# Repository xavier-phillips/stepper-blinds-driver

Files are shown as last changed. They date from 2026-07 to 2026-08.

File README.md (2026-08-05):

<div align="center">

# stepper-blinds-driver

**An ultra-quiet NEMA 17 retrofit driver for beaded-chain roller blinds.**

Xavier Phillips









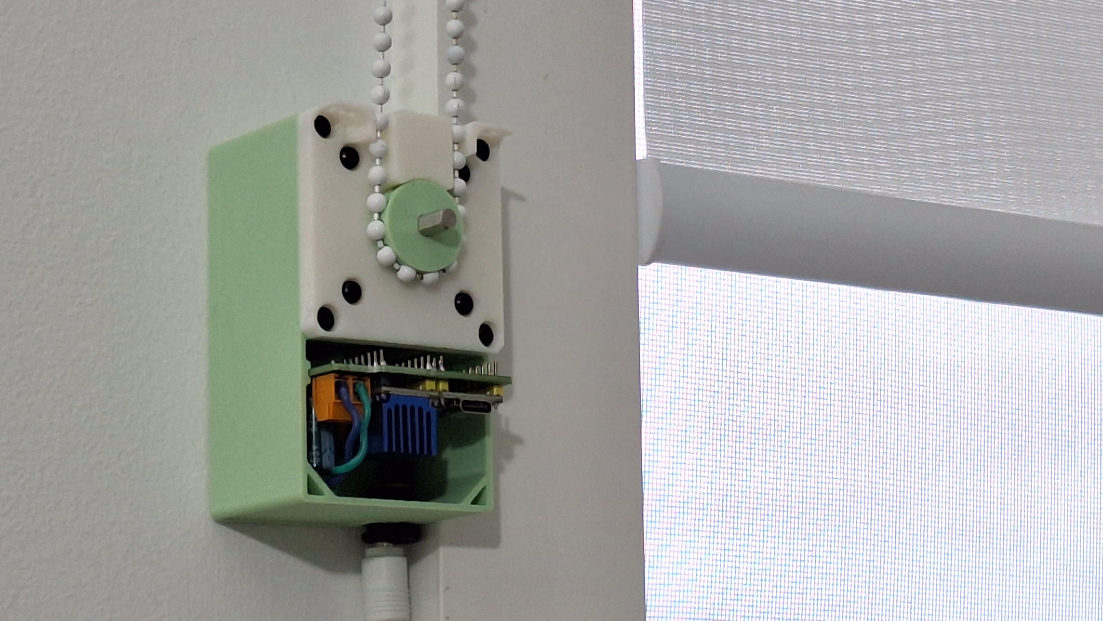
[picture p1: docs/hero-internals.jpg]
Finished device

_The stepper blinds driver with the top lid removed, showing the main sprocket and the custom PCB._

</div>

---

## Contents
- [Overview](#overview)
- [Project Snapshot](#project-snapshot)
- [Technical Skills](#technical-skills)
- [Key Design Decisions](#key-design-decisions)
- [Hardware](#hardware)
- [Control Software](#control-software)
- [Build Log](#build-log)
- [Testing](#testing)
- [What's Next](#whats-next)
- [Reflection](#reflection)
- [Documentation](#documentation)

---

## Overview

### Problem
Opening blinds automatically has a range of benefits:
- Easier to wake up in mornings, and aligns circadian rhythm
- Provides more sunlight during day (for an office, this helps improve mood, among other health benefits)

Commercial options have some limitations:
- Can be very expensive
- Almost all commercial devices use geared DC motors, and are very loud when in operation (>50dB)

### Goal
1. Low-cost (<$100)
2. Compatible with beaded-chain blinds
3. Near-silent (<40dB)

### Features
1. Actuate beaded-chain with positional control (e.g. set to 50%)
   2. High precision is not crucial, aside from the start and end positions. However, end position is a mechanical limit (blinds cannot go further than highest position).
3. Controlled via Google Home or Home Assistant for scheduled automations.
4. Device should be compact
5. Powered externally with power supply (extremely clean, minimal, easy to hide cable)
6. Buttons should be minimised for aesthetic
   7. Possible structure
      1. Ver. 1 - up/down pushbuttons, power toggle. accessible port for microcontroller. no PCB (wires)
      2. Ver. 2 - power toggle only - small, hidden same-colour micro latch switch. hidden port for microcontroller (possibly a friction fit soft tpu plastic cover for it or similar, like a port cover, same colour). PCB.
8. Easily replaceable components (motor, PCB, microcontroller). highest priority for replicability is the cog/sprocket for the beaded chain which MUST be hot swappable in seconds
9. Custom PCB for final product
10. Clean, minimal box design with all internals hidden, mountable to a wall with standard screws

---

## Project Snapshot

### Details

| **Type** | Personal project (no course/folio behind it) |
| --- | --- |
| **Duration** | Started ~30 June 2026, ongoing |
| **Budget** | $90.42 true project cost (target: <$100) |
| **Mechanism** | Beaded-chain actuation, positional control (e.g. set to 50%) |
| **MCU / Control** | ESP32-C6 Mini Dev Board (Serial CLI Firmware v1.0) |
| **Motor / driver** | NEMA 17 Stepper Motor (34mm, 1.5A) + TMC2209 V2.0 Stepper Driver |
| **PCB** | Custom 2-layer PCB for all electrical components |
| **Mechanical CAD** | Onshape |
| **Manufacturing** | 3D printing |

### Specifications

| Spec | Value |
| --- | --- |
| Required pulling force | 1.8kg (bucket-tested - see build log) |
| Noise target | <40dB (commercial cheap models are >50dB) |
| Travel range | Unlimited |
| Holding torque | N/A, designed for counterbalanced or friction-balanced household blinds |
| Power supply | 12V 3A 36W power supply |
| Ecosystem tested against | Google Home or Home Assistant (per scope - not yet tested) |

---

## Technical Skills

| Area | Skills and tools |
| --- | --- |
| Mechanical design | Onshape CAD - hot-swappable cog/sprocket mount for the beaded chain, compact enclosure |
| PCB design | KiCad - custom PCB for final product (goal #7); V1 currently using off-the-shelf breakouts (TMC2209 driver module, MP1584EN buck converter) on a prototype board |
| Embedded programming | C++ / Arduino on ESP32 (Non-blocking stepper driver integration) |
| Smart home integration | Google Home or Home Assistant, for scheduled automations |
| Manufacturing | 3D printing |

---

## Key Design Decisions

| Decision | Options considered | Reasoning |
| --- | --- | --- |
| Motor + driver | Ranked 10 motor setups against the <40dB noise / <$100 cost constraints (full comparison below); shortlisted NEMA 17 + TMC2209, JGY-370 Worm Gear Motor, NEMA 17 (5:1 Planetary Geared) + TMC2209 | This motor is extremely well documented and has a low noise level when paired with the TMC2209 controller. |
| PCB / prototyping approach | Off-the-shelf breakout modules (TMC2209 driver, MP1584EN buck converter) on a prototype board vs. a from-scratch custom PCB | V1 is on protoboard for now; custom PCB for final product is goal #7 |
| Button / enclosure interface | Minimal-none. The device is intended to be controlled wirelessly in the final iteration. Prototypes are controlled via serial CLI. | Buttons should be minimised for aesthetic (goal #5) |

<details>
<summary><strong>Full motor comparison</strong> (from motor research notes)</summary>

> The biggest constraints for the motor are the <40dB requirement and the cost (total cost <$100)

**What impacts motor noise?**
- DC Brushed Motors - Brush scratching
- Geared Motors - Vibrations and friction
- Magnetic hum & coil whine

Overall, the magnitude of these sounds is also proportional to the RPM of the motor, so a slower RPM motor is ideal (and has the additional advantage of making the change in light level more gradual)

| Rank | Motor Setup | Category | Torque (Nm) | Max RPM | RPM Notes | Self-Locking | Approx. Noise Level (dB) | Dimensions (mm) | Volume (cm³) |
|---|---|---|---|---|---|---|---|---|---|
| 1 | NEMA 17 (Standard 42mm) + TMC2209 | Stepper | 0.40 | 400 | Variable | No | 38 | 42.3 x 42.3 x 40.0 | 71.57 |
| 2 | JGY-370 Worm Gear Motor (12V) | Brushed DC | 1.00 | 40 | Gearbox Fixed | Yes | 42 | 76.8 x 32.0 x 25.2 | 61.93 |
| 3 | NEMA 17 (5:1 Planetary Geared) + TMC2209 | Stepper | 1.50 | 80 | Variable | No | 43 | 42.3 x 42.3 x 61.3 | 109.68 |
| 4 | 35BYJ46 Geared Stepper (12V) | Stepper | 0.30 | 30 | Variable | No | 38 | 35.0 x 35.0 x 17.2 | 21.07 |
| 5 | BGM4108 Gimbal Motor + SimpleFOC | BLDC | 0.20 | 400 | Variable | No | 32 | 46.0 x 46.0 x 24.0 | 50.78 |
| 6 | 12V 28BYJ-48 (Modified to Bipolar) | Stepper | 0.10 | 15 | Variable | No | 35 | 28.0 x 28.0 x 19.0 | 14.90 |
| 7 | 25GA-370 Gear Motor (12V) | Brushed DC | 0.50 | 60 | Gearbox Fixed | No | 45 | 25.0 x 25.0 x 52.0 | 32.50 |
| 8 | NEMA 14 + TMC2209 Driver | Stepper | 0.15 | 400 | Variable | No | 38 | 35.0 x 35.0 x 26.0 | 31.85 |
| 9 | N20 Micro Gearmotor (12V, 60 RPM) | Brushed DC | 0.25 | 60 | Gearbox Fixed | No | 45 | 26.0 x 12.0 x 10.0 | 3.12 |
| 10 | MG996R Continuous Rotation Servo | Servo | 0.90 | 100 | Variable | No | 50 | 40.7 x 19.7 x 42.9 | 34.40 |

**Shortlist**

*1. NEMA 17 + TMC2209* - This motor is extremely well documented and has a low noise level when paired with the TMC2209 controller.

*2. JGY-370 Worm Gear Motor* - This is a slightly louder, more powerful alternative to the NEMA, the second best option if the NEMA turns out to be underpowered in torque (0.40 Nm vs 1.00 Nm). Has an additional benefit of being self-locking. Slightly above the noise limit by 2dB which is an acceptable margin.

*3. NEMA 17 (5:1 Planetary Geared) + TMC2209* - Same motor as Option 1, but geared to increase torque and reduce max RPM. Similar noise level and torque to Option 2, but ranked lower due to increased complexity.

</details>

---

## Hardware

### Mechanical (Onshape)
The main mechanical component is the mount, featuring two compartments. A thick-walled compartment which is load-bearing and contains the NEMA17, in addition to a thin-walled circuit compartment. 

To connect the NEMA17 to the mount, there is a face plate, which also features guides for the beaded-chain to be routed through.

There's also a cosmetic lid which is friction-fit using two pins for alignment and security, hiding the internal circuit while being easy to remove.

The sprocket is parametrically designed based on the following formulas.

The box features hexagonal ventilation holes which balance structural integrity and FDM manufacturability with sufficient surface area for thermal convection to prevent overheating.

### Electronics (KiCad)
The electronics involved in this project are for controlling and powering the motor. The ESP32 is the brain, allowing programmed movement logic and eventually communication with Google Home and other smart home systems via Matter over WiFi. The TMC2209 acts as an interface between the ESP32 and the NEMA17, and via the StealthChop2 feature, it allows ultra-quiet motor movement. The MP1584EN is a simple buck converter to step down the 12V from the power supply to the 5V required for the ESP32. 

I decided to use a custom PCB because I wanted to make multiple of the device, and eventually open-source it, so I decided inserting components into a PCB would be much easier than wiring spaghetti and frustrating breadboarding. It also gave me a chance to upskill KiCAD and learn about circuit schematics, rule checkers, and the PCB development and manufacturing process.

**BOM**

| Component | Source | Pack Size (Bought) | Qty Required | Pack Cost (AUD) | True Project Cost (AUD) |
|---|:---:|:---:|:---:|:---:|:---:|
| ESP32-C6 Mini Dev Board | Amazon AU | 1 | 1 | $25.01 | $25.01 |
| 12V 3A 36W Power Supply | Amazon AU | 1 | 1 | $21.99 | $21.99 |
| NEMA 17 Stepper Motor (34mm, 1.5A) | Amazon AU | 1 | 1 | $20.99 | $20.99 |
| TMC2209 V2.0 Stepper Driver | Amazon AU | 5 | 1 | $37.03 | $7.41 |
| MP1584EN 3A DC-DC Buck Converter | Amazon AU | 15 | 1 | $18.87 | $1.26 |
| Custom 2-Layer PCB | JLCPCB | 5 | 1 | $2.00 | $0.40 |
| M3 Button Head Screw Kit | Amazon AU | 300 | 8 | $10.99 | $0.29 |
| M3 Nylon Standoffs & Nuts Kit | Amazon AU | 320 | 4 | $12.99 | $0.16 |
| 3M VHB Double Sided Tape | Amazon AU | 33m | 10 cm | $12.99 | $0.04 |
| 2.1mmx5.5mm DC Power Jack (Panel Mount) | Amazon AU | 30 | 1 | $16.89 | $0.56 |
| 100µF 50V Electrolytic Capacitor (Polarized) | Jaycar Electronics | 1 | 1 | $1.00 | $1.00 |
| 60/40 Rosin Core Solder 0.71mm | Workshop | 15g | Variable | $0.00 | $0.00 |
| 24 AWG Solid Core Hookup Wire | Workshop | N/A | Variable | $0.00 | $0.00 |
| **Totals** | | | | **$180.75** | **$79.11** |

---

## Control Software
I wanted to keep this deliberately simple and write it fully myself so I could understand how the stepper control loop works, rather than relying on agentic tools to write something complex that I wouldn't fully understand under the hood.

**What it does:**
- Serial-based control to move to a pre-defined top and bottom position for the blinds
- Pause command to cancel movement with smooth acceleration.

**What it deliberately doesn't do (and why):**
- Other features (e.g. Matter over WiFi, auto calibration) have been left out due to time constraints for now and will be developed further in the future.

**Walkthrough**

* **`read_int()`:** Serial user input parser that checks for user commands and accepts valid inputs as commands (`0: Stop`, `1: Top`, `2: Bottom`).
* **`FastAccelStepper` Engine:** Asynchronously drives the STEP/DIR signal generation using ESP32 hardware timers, allowing smooth acceleration and deceleration ramps in the background.

---

# Build Log

### 2026-06-30 - Measuring required pull force

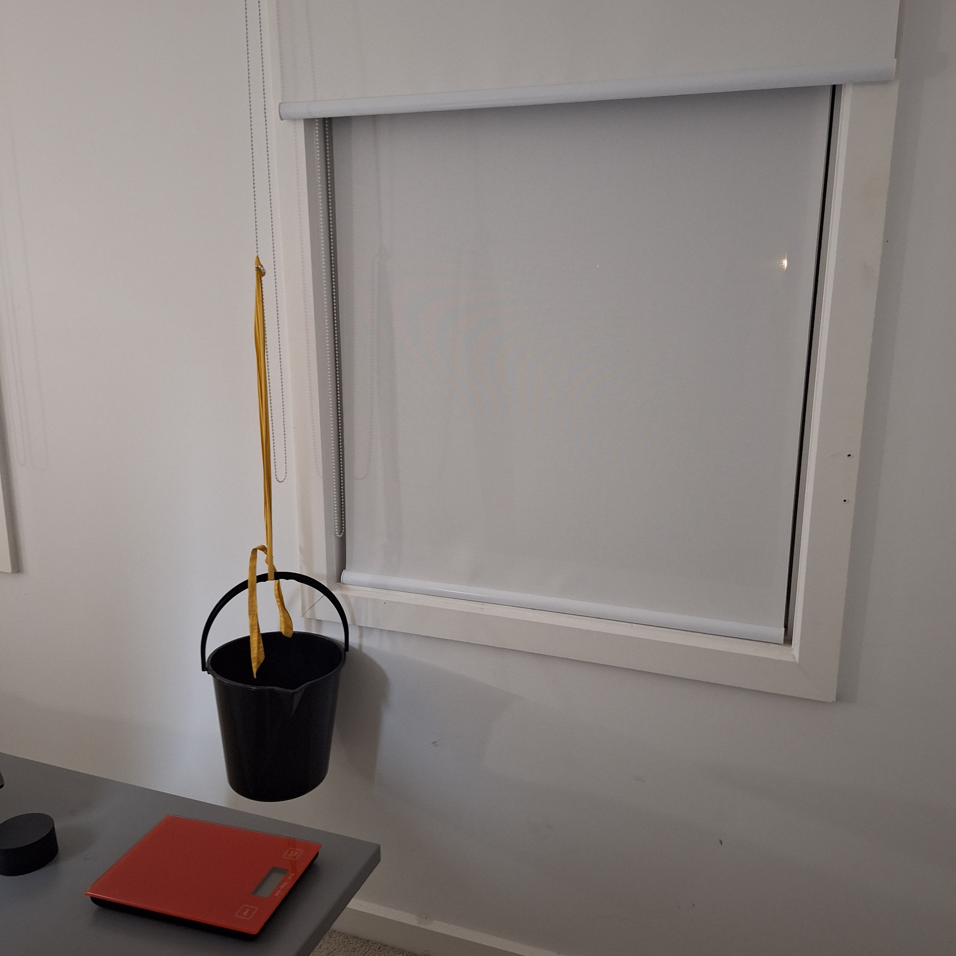
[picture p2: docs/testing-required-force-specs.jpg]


- Used a water bucket attached to the blinds to measure the force required to move them.
- At 1.7 kg, the blinds remained stationary. At 1.8 kg, the blinds were able to move.
- The 20 mm NEMA17 was determined to have insufficient torque, leading to the decision to use the 34 mm NEMA17 instead.

### 2026-07-02 - Initial CAD design

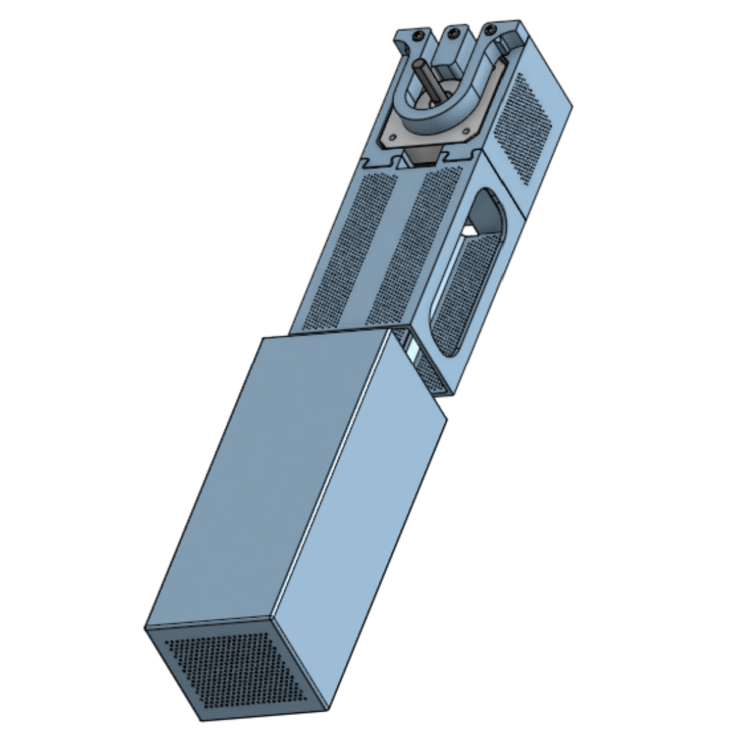
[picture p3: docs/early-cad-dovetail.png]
Initial CAD design


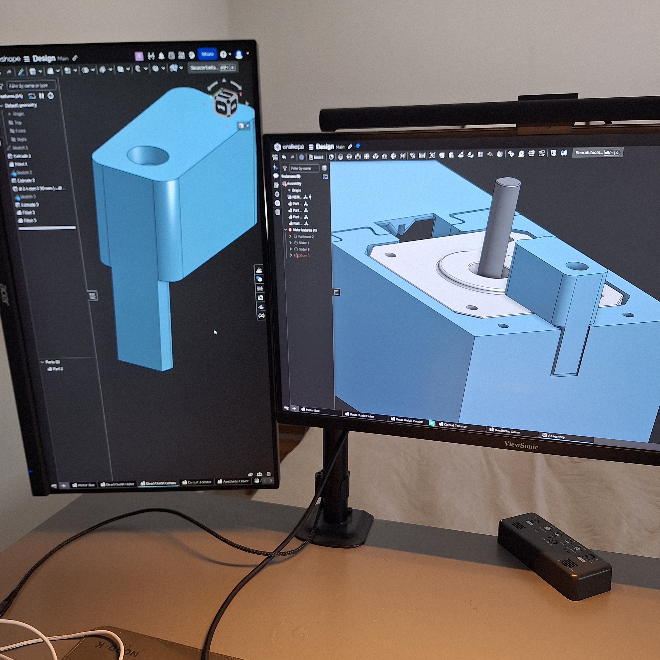
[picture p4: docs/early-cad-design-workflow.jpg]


 - This design has a removable circuit box area, using dovetail cutouts. It also has removable guides for the beaded chains, secured by M2 screws.

### 2026-07-05 - Perfboard Assembly

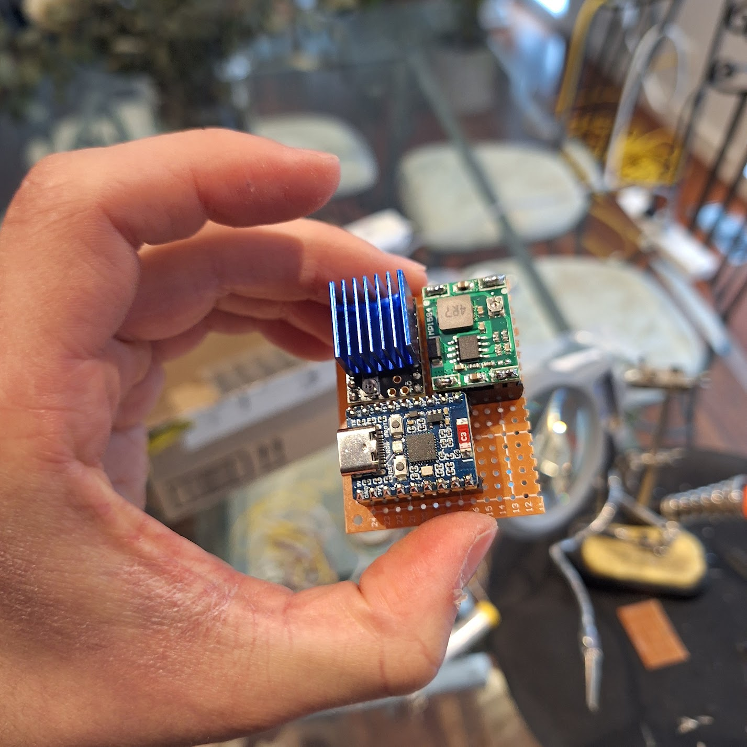
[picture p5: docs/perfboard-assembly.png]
Perfboard Assembly


 - Image of the components laid out on a perfboard. I've cut the perfboard down to a smaller size for compactness in this image, but for later perfboard iterations I used the full size, just for ease of wiring and troubleshooting (since it was only a prototype, the compactness was evaluated as somewhat irrelevant)

### 2026-07-07 - PCB Design 1

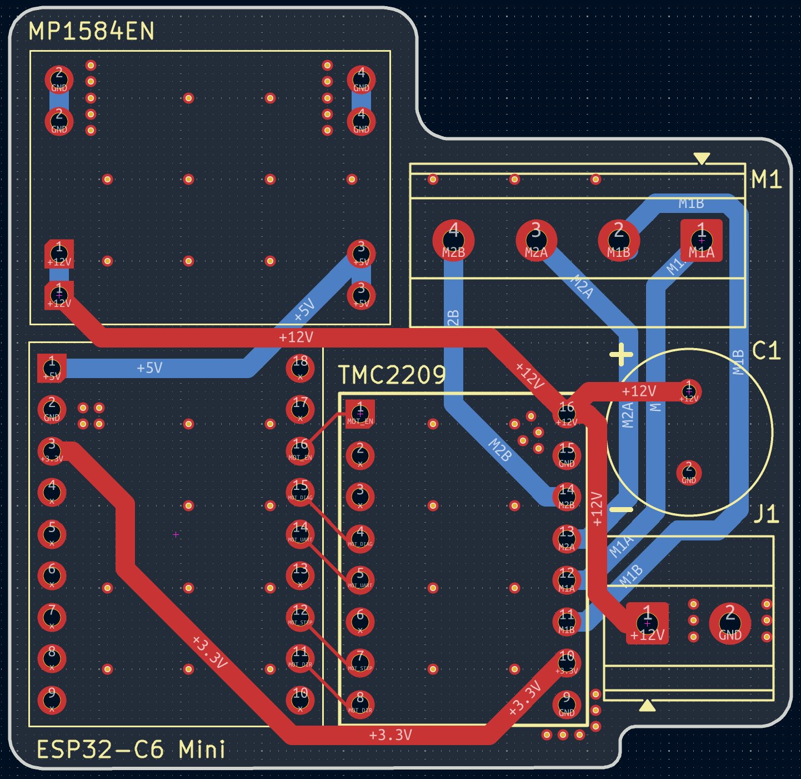
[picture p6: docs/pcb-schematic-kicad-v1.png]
PCB Design 1


### 2026-07-10 - PCB Design 2

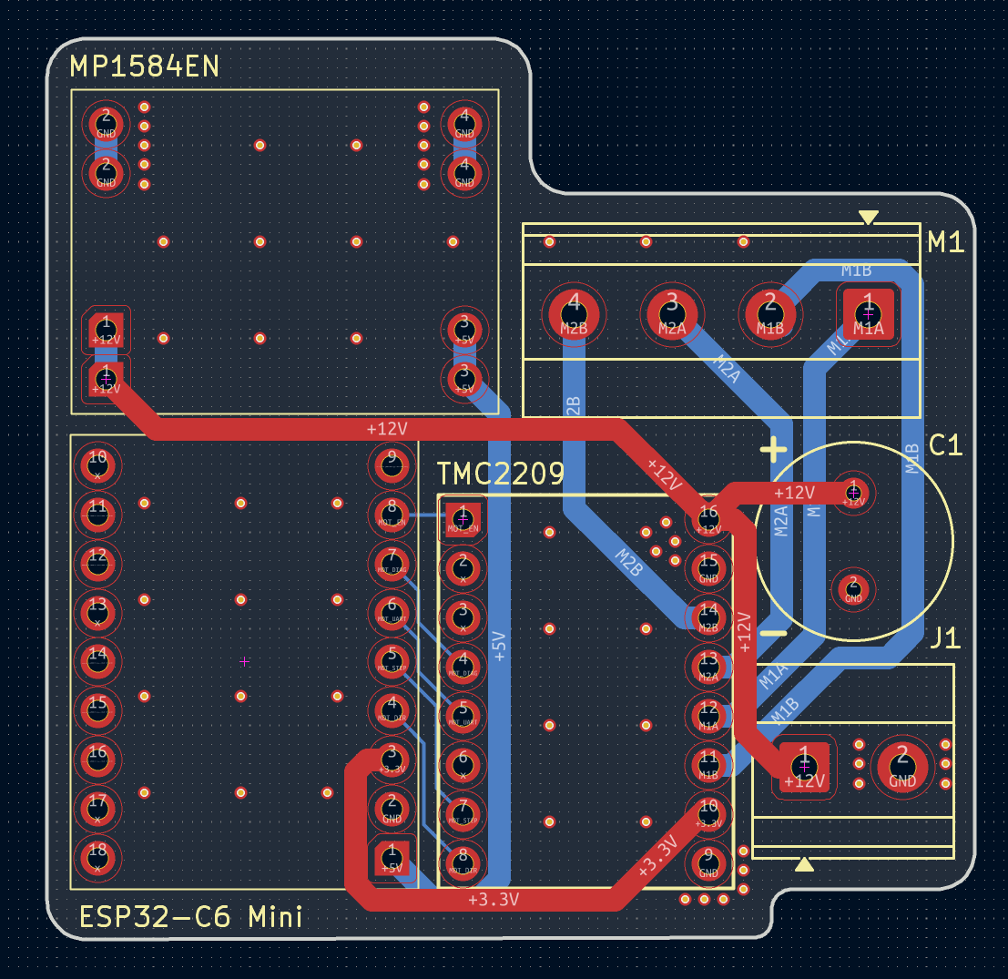
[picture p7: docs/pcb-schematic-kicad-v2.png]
PCB Design 2


- Modified the PCB schematic in KiCAD to flip the footprint of the ESP32C6 by 180 degrees. This ensures that it can be wired correctly while having the USB port point towards the edge of the board, instead of the centre. Code was also updated to reflect the new pins.

### 2026-07-21 - Control Software Draft

```cpp
#include <Arduino.h>
#include <FastAccelStepper.h>

constexpr int PIN_EN = 14;
constexpr int PIN_SPREAD = 15;
constexpr int PIN_UART = 18;
constexpr int PIN_STEP = 20;
constexpr int PIN_DIR = 21;

constexpr int SPEED = 500;  // step per sec
constexpr int ACCEL = 1000; // step per sec^2

constexpr int TOP_POSITION = 0;       // steps
constexpr int BOTTOM_POSITION = 1000; // steps

enum user_input
{
  PAUSE,
  TOP,
  BOTTOM,
  OPTIONS_COUNT
};

user_input command = PAUSE;

int read_int()
{
  int command = -1;

  if (Serial.available() > 0)
  {
    command = Serial.parseInt();

    Serial.printf("Command received: %d\n", command);
  }

  return command;
};

FastAccelStepperEngine engine = FastAccelStepperEngine();
FastAccelStepper *stepper = nullptr;

void setup()
{
  pinMode(PIN_STEP, OUTPUT);
  digitalWrite(PIN_SPREAD, LOW);

  Serial.begin(115200);
  delay(1000);

  engine.init();

  stepper = engine.stepperConnectToPin(PIN_STEP);

  if (stepper)
  {
    Serial.println("SUCCESS: Stepper connected!");

    stepper->setDirectionPin(PIN_DIR);
    stepper->setEnablePin(PIN_EN);
    stepper->setAutoEnable(true);
    stepper->setSpeedInHz(SPEED);
    stepper->setAcceleration(ACCEL);
    stepper->setCurrentPosition(0);
  }
  else
  {
    Serial.println("ERROR: Stepper failed to connect.");
  }
}

void loop()
{

  command = static_cast<user_input>(read_int());

  if (command != -1)
  {
    Serial.printf("Current Position: %d Enter an option:\n\t0.Pause\n\t1. Move Top\n\t2. Move Bottom\n", stepper->getCurrentPosition());

    switch (command)
    {
    case PAUSE:
      Serial.println("Action: STOP");
      stepper->stopMove();
      break;

    case TOP:
      Serial.println("Action: TOP");
      stepper->moveTo(TOP_POSITION, false);
      break;

    case BOTTOM:
      Serial.println("Action: BOTTOM");
      stepper->moveTo(BOTTOM_POSITION, false);
      break;

    default:
      Serial.printf("Invalid command! Enter a valid integer between 1 and %d.\n", OPTIONS_COUNT);
      break;
    }
  }
}
```
 - Just a basic serial-control script for testing basic functionality (movement up, down, and pausing)

### 2026-07-24 - CAD Design 2

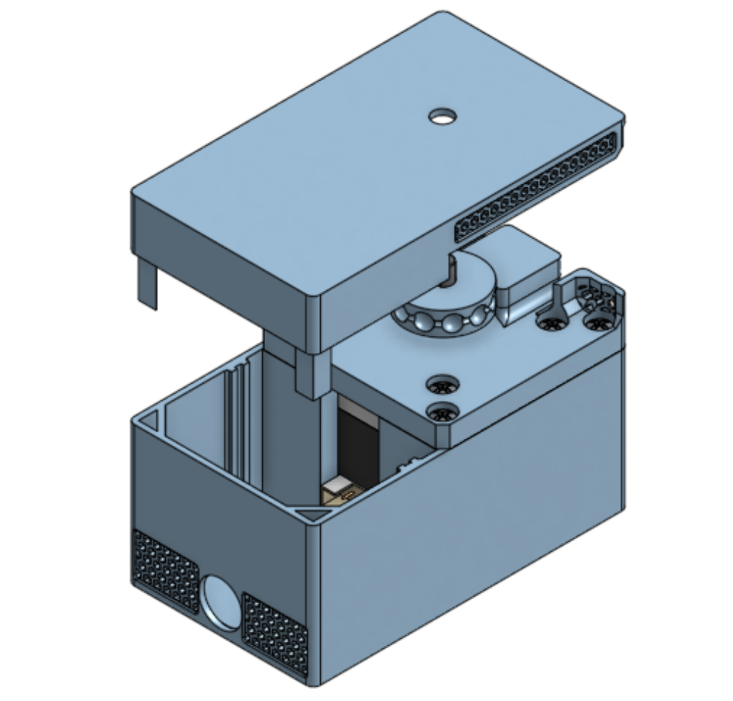
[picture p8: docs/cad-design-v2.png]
CAD Design 2


 - This was a major transition. The two-box dovetail architecture was replaced with a single box with two compartments. 

### 2026-07-30 - Motor Testing

- Upon arrival of the board (**2026-07-30**) and initial basic testing of roller blind movement (a short test program), I determined that the NEMA17 tended to stall quite easily. Upon closer inspection and troubleshooting (including verifying that it did work with a much lighter, smaller roller blind), I determined that the cause was simply insufficient current. The 12V wall adapter I was using only had a rated current of 1A, much less than the planned 3A.
- Order a 12V 3A power supply ASAP, in order to provide sufficient power for the NEMA17 to lift basic blinds.

---

## Testing

| Test | Result |
| --- | --- |
| Bucket test - required pulling force | 1.8kg confirmed |
| Noise level (<40dB target) | Not yet tested  |

---

## What's Next

- The next step is writing the implementation that includes Matter, rather than the basic hard-coded values the script currently uses. 
	- For the implementation, I want to keep it buttonless for aesthetics and simplicity of circuitry. So I'm planning to use StallGuard to determine increased resistance at the top of the range of motion (ROM) for calibration, as well as a reduced resistance at the bottom of ROM.

---

## Reflection

I learned a massive amount from this project. On the CAD side, I learned about using variables in my designs, rather than "magic numbers" for dimensions, so everything in my design is fully adjustable via the variables table. I also learned about a lot more Onshape's sketch tools (tangent, normal, and perpendicular constraints), as well as their 3D tools (Featurescripts like Grid Extrude for ventilation, alongside operations like revolve which I used for the sprocket). 

I also learned KiCAD from scratch during this project, which was a great learning experience and upskilling opportunity into a new field. Historically I used graphical software like Canva or Illustrator for circuit diagrams, but learning how to write proper, verified schematics was really enjoyable, and seeing my own custom-designed PCB arrive was extremely rewarding. Contrary to what I used to assume about PCBs, it actually _saved_ me time, as I used to have to spend weeks fiddling with breadboards because I didn't take the time to plan my circuit thoroughly. That, combined with the time saved from soldering (only took ~10min to solder the entire PCB!), allowed me to finalise all electronics in about a week.

---

## Documentation

- Firmware Code: [`/firmware`](firmware/)
- PCB (Schematic + Gerbers): [`/hardware/pcb`](hardware/pcb/)
- CAD Files: [`/hardware/cad`](hardware/cad/)

## Acknowledgements & License

[gin66/FastAccelStepper: A high speed stepper library for Atmega 168/328p (nano), Atmega32u4, Atmega 2560, ESP32, ESP32S2, ESP32S3, ESP32C3, ESP32C6, Atmel SAM Due, Raspberry pi pico and pico 2](https://github.com/gin66/FastAccelStepper)

This project is licensed under the MIT License. See the [LICENSE](LICENSE) file for details.

<p align="center"><sub>Personal project, July 2026.</sub></p>

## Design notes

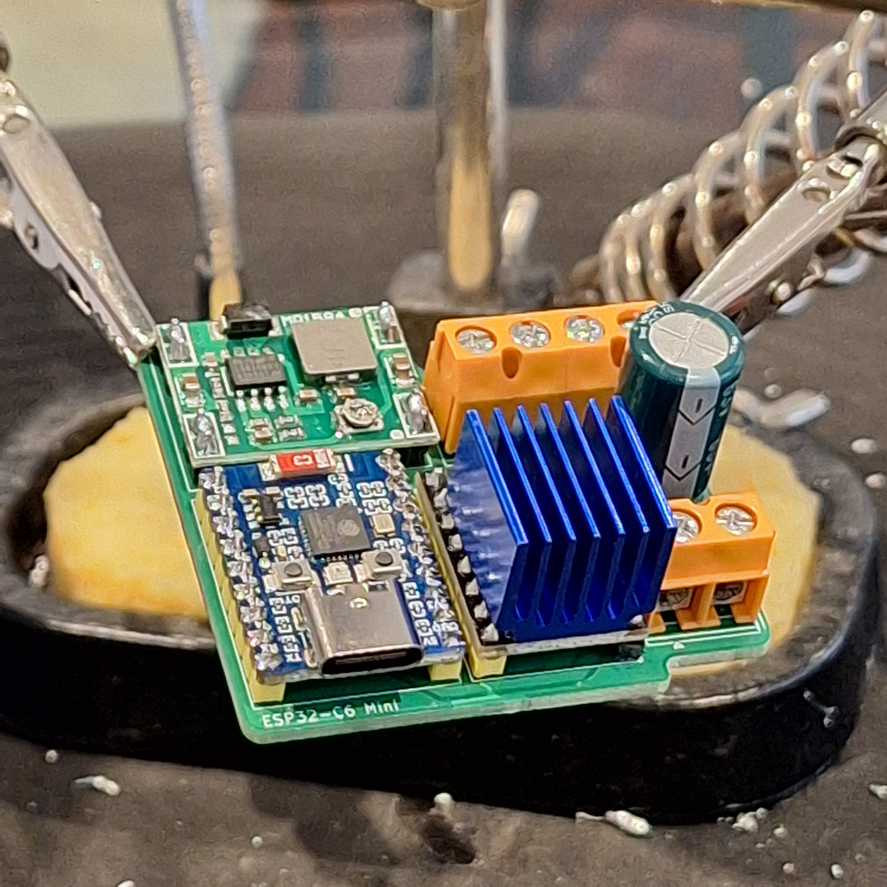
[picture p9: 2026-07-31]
docs/completed-pcb.jpg

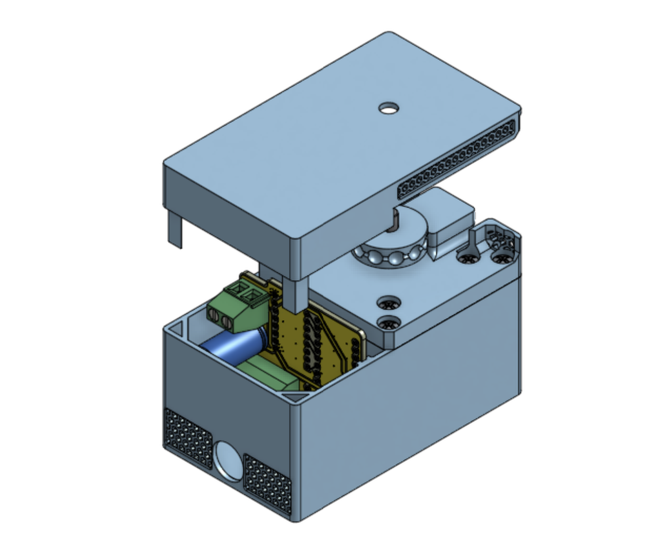
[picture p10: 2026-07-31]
docs/hero-uncovered.png

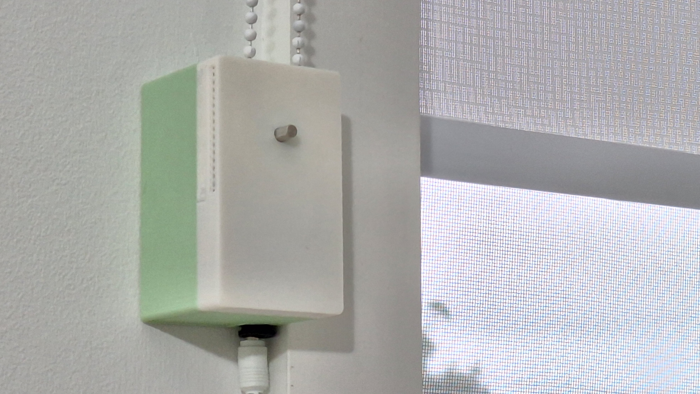
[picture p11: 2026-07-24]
docs/hero-covered.jpg

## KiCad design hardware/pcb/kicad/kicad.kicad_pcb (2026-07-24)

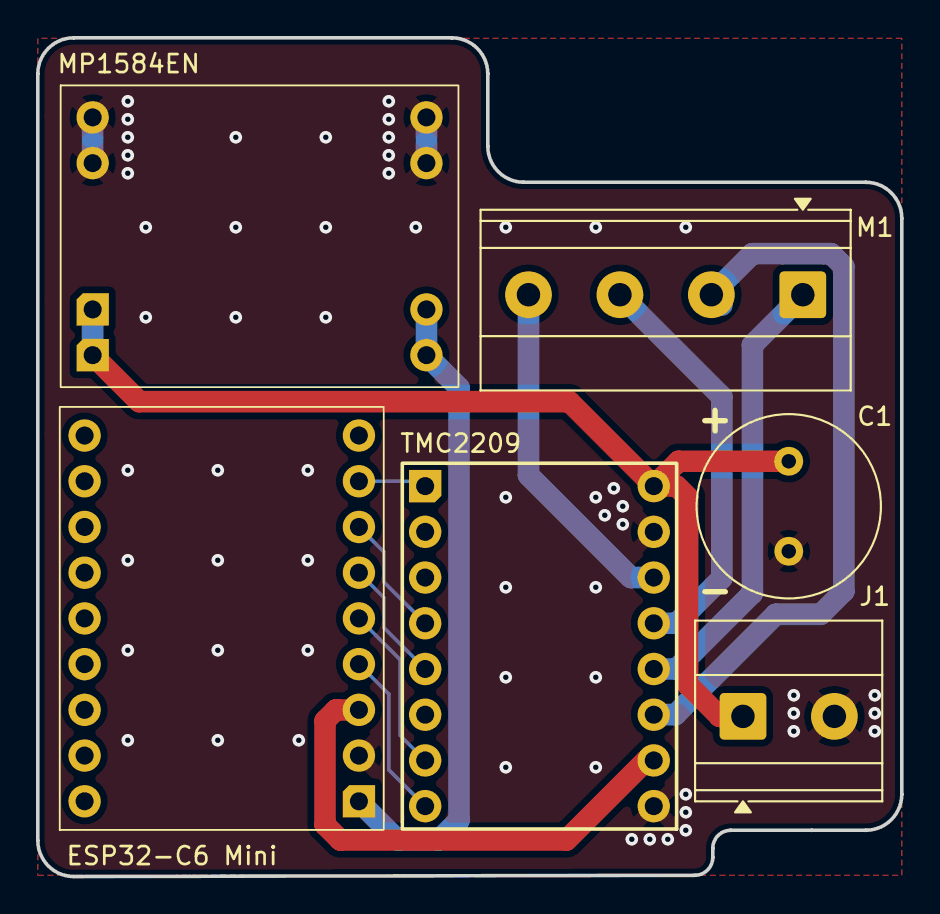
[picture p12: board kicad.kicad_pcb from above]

Board: 2 copper layers, 48.0 x 46.6 mm, 6 parts (0 on the bottom side), 13 nets.

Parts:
C1: 100µF; C_Radial_D10.0mm_H20.0mm_P5.00mm
ESP32-C6-Super-Mini1: ESP32-C6-Super-Mini-Header
J1: Barrel_Jack; TerminalBlock_Phoenix_MKDS-1,5-2-5.08_1x02_P5.08mm_Horizont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
M1: Stepper_Motor_bipolar; TerminalBlock_Phoenix_MKDS-1,5-4-5.08_1x04_P5.08mm_Horizont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
MP1584EN1: MP1584EN-Module
TMC2209: TMC2209-Module

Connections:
+3.3V: ESP32-C6-Super-Mini1.3 (3V3), TMC2209.10 (VIO)
+5V: ESP32-C6-Super-Mini1.1 (5V), MP1584EN1.3 (OUT+)
+12V: C1.1, J1.1, MP1584EN1.1 (IN+), TMC2209.16 (VM)
/M1A: M1.1, TMC2209.12 (M1A)
/M1B: M1.2 (-_2), TMC2209.11 (M1B)
/M2A: M1.3, TMC2209.13 (M2A)
/M2B: M1.4, TMC2209.14 (M2B)
/MOT_DIAG: ESP32-C6-Super-Mini1.7 (GP3), TMC2209.4 (SPREAD)
/MOT_DIR: ESP32-C6-Super-Mini1.4 (GP0), TMC2209.8 (DIR)
/MOT_EN: ESP32-C6-Super-Mini1.8 (GP4), TMC2209.1 (EN)
/MOT_STEP: ESP32-C6-Super-Mini1.5 (GP1), TMC2209.7 (STEP)
/MOT_UART: ESP32-C6-Super-Mini1.6 (GP2), TMC2209.5 (PDN_UART1)
GND: C1.2, ESP32-C6-Super-Mini1.2 (GND), J1.2, MP1584EN1.2 (IN-), MP1584EN1.4 (OUT-), TMC2209.9 (GND), TMC2209.15 (GND)

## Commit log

2026-07-25 Added CAD README
2026-08-05 Update BOM
2026-10-13 Correct overstated claims in README
    Match the README to the project record: skewer picking and laptop detection (AutoBerryPicker), calculated rather than measured force (exoARM), unmeasured noise and the shipped custom PCB (stepper-blinds-driver).
2026-10-17 Distinguish editable CAD from local print exports
